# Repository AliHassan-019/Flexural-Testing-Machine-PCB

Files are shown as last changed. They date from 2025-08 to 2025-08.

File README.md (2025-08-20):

# Flexural Testing Machine — Control PCB

**Main control board for a catheter flexural/kink test rig with motion control, load-cell acquisition, and DWIN HMI.**

> **Open-hardware control PCB that advances a catheter via stepper, applies a defined bend angle via servo, and measures force with a 1 kg load cell to detect kink onset.**

---







---

## Quick Links

- [Schematic PDF](hardware/altium/flexural-pcb_rev1.0_sch.pdf)
- [PCB Layout](hardware/altium/flexural-pcb_rev1.0_pcb.pdf)
- [Fabrication Bundle](outputs/fab/flexural-pcb_rev1.0_fab.zip)
- [Assembly Bundle](outputs/assy/flexural-pcb_rev1.0_assy.zip)
- [Issues](../../issues)
- [Discussions](../../discussions)

---

## Table of Contents

1. [Overview](#overview)
2. [Safety & Regulatory Notice](#safety--regulatory-notice)
3. [Highlights / Features](#highlights--features)
4. [System / Block Diagram](#system--block-diagram)
5. [Power Architecture](#power-architecture)
6. [Schematic Overview](#schematic-overview)
7. [Connectors & Pinouts](#connectors--pinouts)
8. [Bill of Materials (BOM)](#bill-of-materials-bom)
9. [PCB Stackup & Rules](#pcb-stackup--rules)
10. [Layout Notes & 3D/Mechanical](#layout-notes--3dmechanical)
11. [EDA Tooling & Directory Structure](#eda-tooling--directory-structure)
12. [Design Rules & Constraints](#design-rules--constraints)
13. [Manufacturing: Fabrication Outputs](#manufacturing-fabrication-outputs)
14. [Manufacturing: Assembly Outputs](#manufacturing-assembly-outputs)
15. [DFM / DFT Guidance](#dfm--dft-guidance)
16. [Programming & Interfaces](#programming--interfaces)
17. [Calibration & Bring-Up](#calibration--bring-up)
18. [Validation & Test Records](#validation--test-records)
19. [Known Issues / Errata](#known-issues--errata)
20. [Roadmap](#roadmap)
21. [Contributing](#contributing)
23. [License](#license)
24. [Acknowledgments & Citation](#acknowledgments--citation)
25. [Changelog](#changelog)

---

## Overview

The **Flexural Testing Machine — Control PCB** is the main controller for a bench-top R&D device designed to measure the force at which catheters begin to kink under controlled bending. The PCB orchestrates the workflow: advancing the catheter, bending to a preset angle, acquiring force data, detecting kink onset, graphing/logging results, and reporting. Not intended for clinical or patient use.

**Workflow Summary:**
1. Advance catheter via stepper motor.
2. Bend catheter to defined angle using servo.
3. Acquire force via load cell and NAU7802 AFE.
4. Detect kink onset (force spike/drop).
5. Display/log results via DWIN HMI and USB.
6. Stop and report.

---

## Safety & Regulatory Notice

> ⚠️ **For R&D bench testing only; NOT a clinical device.**
>
> - Observe electrical safety protocols.
> - Beware of pinch hazards and motorized motion.
> - No claim of compliance with IEC/ISO standards.
> - References to standards are for design context only.

---

## Highlights / Features

- **MCU:** STM32L432KBT6 (Cortex-M4F, 80 MHz, 256 KB Flash, 64 KB SRAM, LQFP-32)
- **HMI:** DWIN 4.3″ DGUS II TFT Touch (DMT48270T043, UART-TTL, 5 V)
- **Stepper Driver:** TB6600 external module (optocoupled, 24 V)
- **Servo Output:** PWM 50 Hz, 1–2 ms, 6 V rail
- **Force Sensor:** 1 kg 4-wire load cell (1.0–2.0 mV/V)
- **Load-Cell ADC/AFE:** NAU7802CGI (24-bit Δ-Σ, I²C, 3.3 V)
- **Power Input:** 24 V DC (20–26 V), reverse/surge protected
- **Regulators:** MP1584EN (24 V→6 V/5 V, 3 A), AP2112K-3.3 (600 mA), TPS7A2033PDBVR (300 mA, low-noise)
- **Level Shifting/Protection:** 74AHCT125N, SN74LVC2T45DCUR, TPD4E1U06DQAR
- **PC Interface:** CP2102N USB-UART, Micro-B
- **Programming:** 10-pin 1.27 mm Cortex-M SWD header
- **Clocks:** 32.768 kHz LSE, 8 MHz HSE (fitted)
- **Discrete IO:** Limit/Home switches (x2), E-Stop (ISO1212D, 24 V)
- **Connectors:** Phoenix MCV 5.08, JST-XH, Molex Micro-B
- **Protections/Filters:** MBRS340, TVS diodes, ferrite beads, bulk caps
- **Decoupling:** 100 nF + 4.7 µF per device, anti-aliasing RC
- **Form Factor:** 120 × 90 mm, 4× M3 mounting holes, 3 mm keep-outs

---

## System / Block Diagram

```mermaid
flowchart LR
  MCU[STM32L432KBT6]
  HMI[DWIN 4.3in DGUS HMI]
  AFE[NAU7802 Load Cell ADC]
  SERVO[Servo Header PWM 6V GND]
  TB6600[TB6600 Driver IO]
  SWD[SWD Programming]
  USB[CP2102N USB CDC]
  LC[1 kg Load Cell]
  VIN[24V Input]
  PROT[Reverse and TVS]
  B6[MP1584 6V 3A]
  B5[MP1584 5V 3A]
  LDOd[AP2112K 3.3V Digital]
  FB[Ferrite]
  LDOa[TPS7A2033 Analog]

  MCU --> HMI
  MCU --> AFE
  MCU --> SERVO
  MCU --> TB6600
  MCU --> SWD
  MCU --> USB
  LC --> AFE
  VIN --> PROT
  PROT --> B6
  PROT --> B5
  B6 --> SERVO
  B5 --> HMI
  B5 --> LDOd
  B5 --> FB
  FB --> LDOa
  LDOd --> MCU
  LDOa --> AFE

```

---

## Power Architecture

```mermaid
flowchart TD
  IN[24V DC Input 20-26V]
  P24[Protected 24V]
  V6[6V Servo Rail 3A]
  V5[5V Rail 3A]
  V33D[3.3V Digital]
  V33A[3.3V Analog]

  IN --> P24
  P24 --> V6
  P24 --> V5
  V5 --> V33D
  V5 --> V33A

```

---

## Schematic Overview

- **Pages:**
	- MCU Core & Clocks
	- Power & Regulation
	- TB6600 Stepper IO
	- Servo Output
	- Load Cell & NAU7802 AFE
	- DWIN HMI UART
	- USB/CP2102N
	- SWD Programming
	- E-Stop & Limit Switches
- **Key Circuits:**
	- Reset: NRST RC (10 kΩ/100 nF)
	- BOOT0: 10 kΩ pulldown
	- Decoupling: 100 nF at each VDD, 4.7 µF bulk per IC
	- Anti-aliasing: 1 kΩ/0.1 µF on load cell SIG±

---

## Connectors & Pinouts

| Name | RefDes | Type | Pitch | Pin# | Signal(s) | Dir | Voltage | Notes |
|---|---|---|---|---|---|---|---|---|
| Power In | J1 | Phoenix MCV  | 5.08  | 2 | +24V, GND | In | 24 V | Reverse/surge protected |
| TB6600 PUL | J2 | Phoenix MCV  | 5.08  | 2 | PUL+, PUL− | Out | 5 V | Optocoupled, level shifted |
| TB6600 DIR | J3 | Phoenix MCV  | 5.08  | 2 | DIR+, DIR− | Out | 5 V | Optocoupled, level shifted |
| TB6600 ENA | J4 | Phoenix MCV  | 5.08  | 2 | ENA+, ENA− | Out | 5 V | Optocoupled, level shifted |
| Servo | J5 | JST-XH | 2.54  | 3 | PWM, +6V, GND | Out | 6 V | Standard RC servo |
| Load Cell | J6 | JST-XH | 2.54  | 6 | EX+, EX−, SIG+, SIG−, SEN+, SEN− | In | 3.3 V | 4-wire, shielded |
| DWIN HMI | J7 | JST-XH | 2.54  | 4 | 5V, GND, TXD, RXD | Bi | 5 V/3.3 V | UART, level shifted |
| Limit/Home | J8/J9  | JST-XH | 2.54  | 3 | GND, SIG, 3.3V | In | 3.3 V | RC debounce, pull-up |
| E-Stop | J10 | Phoenix MCV  | 5.08  | 2 | 24V, GND | In | 24 V | ISO1212D input |
| USB | J11 | Molex Micro-B| — | 5 | VBUS, D+, D−, ID, GND | Bi | 5 V | CP2102N bridge |
| SWD | J12 | Samtec FTSH  | 1.27  | 10 | SWDIO, SWCLK, NRST, GND, 3.3V | Bi | 3.3 V | Programming/debug |

---

## Bill of Materials (BOM)

| Item | Qty | Designators | Value/Spec | Description | Package | Manufacturer | MPN | Alt MPN | Distributor | Lifecycle | Notes | Status |
|---|-----|---|---|---|---|---|-----|---|---|---|---|---|
| MCU | 1 | U1 | STM32L432KBT6 | ARM Cortex-M4F, 80 MHz | LQFP-32 | STMicro | STM32L432KBT6 | — | Digi-Key | Active | Main controller | Fitted |
| HMI | 1 | LCD1 | DMT48270T043 | 4.3" TFT Touch | — | DWIN | DMT48270T043 | — | DWIN | Active | UART-TTL | Fitted |
| Stepper Driver | 1 | — | TB6600 | External module | — | Toshiba | TB6600 | — | Amazon | Active | Optocoupled | Fitted |
| Servo | 1 | — | Standard RC | PWM 50 Hz | — | Futaba | S3003 | MG995 | Amazon | Active | 6 V rail | Fitted |
| Load Cell | 1 | — | 1 kg | 4-wire, 1.0–2.0 mV/V | — | CZL | CZL635 | — | AliExpress | Active | Shielded | Fitted |
| Load Cell AFE | 1 | U2 | NAU7802CGI | 24-bit Δ-Σ ADC | TSSOP-16 | Nuvoton | NAU7802CGI | — | Digi-Key | Active | I²C | Fitted |
| USB-UART | 1 | U3 | CP2102N-A02-GQFN20 | USB bridge | QFN-20 | Silicon Labs | CP2102N-A02-GQFN20 | — | Digi-Key | Active | Micro-B | Fitted |
| SWD Header | 1 | J12 | FTSH-105-01-F-D-K | 10-pin, 1.27 mm | — | Samtec | FTSH-105-01-F-D-K | — | Digi-Key | Active | Programming | Fitted |
| Buck Regulator | 2 | U4/U5 | MP1584EN | 24V→6V/5V, 3A | SOIC-8 | MPS | MP1584EN | — | Digi-Key | Active | Servo/HMI rails | Fitted |
| LDO (Digital) | 1 | U6 | AP2112K-3.3 | 5V→3.3V, 600mA | SOT-23-5 | Diodes Inc. | AP2112K-3.3 | — | Digi-Key | Active | Digital 3.3V | Fitted |
| LDO (Analog) | 1 | U7 | TPS7A2033PDBVR | 5V→3.3V, 300mA | SOT-23-5 | TI | TPS7A2033PDBVR | — | Digi-Key | Active | Analog 3.3V | Fitted |
| Level Shifter | 1 | U8 | 74AHCT125N | 5V, 3.3V logic | DIP-14 | Nexperia | 74AHCT125N | — | Digi-Key | Active | TB6600 IO | Fitted |
| UART Translator | 1 | U9 | SN74LVC2T45DCUR | Bi-dir, 3.3V↔5V | VSSOP-8 | TI | SN74LVC2T45DCUR | — | Digi-Key | Active | HMI UART | Fitted |
| ESD Protection | 1 | U10 | TPD4E1U06DQAR | USB ESD | QFN-10 | TI | TPD4E1U06DQAR | — | Digi-Key | Active | USB | Fitted |
| E-Stop Input | 1 | U11 | ISO1212D | 24V digital in | SOIC-8 | TI | ISO1212D | — | Digi-Key | Active | Galvanic | Fitted |
| LSE Crystal | 1 | Y1 | ABS25-32.768KHZ-1-T | 32.768 kHz | — | Abracon | ABS25-32.768KHZ-1-T | — | Digi-Key | Active | RTC | Fitted |
| HSE Crystal | 1 | Y2 | ABM8G-8.000MHZ-18-D2Y-T | 8 MHz | — | Abracon | ABM8G-8.000MHZ-18-D2Y-T | — | Digi-Key | Active | Fitted | Fitted |
| TVS Diode | 3 | D1/D2/D3 | SMBJ36A/SMBJ5.0A/SMAJ6.0A | TVS | SMB | Littelfuse | SMBJ36A | SMBJ5.0A | Digi-Key | Active | Surge/ESD | Fitted |
| Schottky Diode | 1 | D4 | MBRS340 | Reverse protection | DPAK | ON Semi | MBRS340 | — | Digi-Key | Active | Input | Fitted |
| Ferrite Bead | 1 | FB1 | BLM21PG121SN1D | 120 Ω @ 100 MHz | 0805 | Murata | BLM21PG121SN1D | — | Digi-Key | Active | Analog 3.3V | Fitted |
| Bulk Cap | 4 | C1–C4 | 470 µF | Low-ESR | Radial | Panasonic | EEU-FR1V471 | — | Digi-Key | Active | Power rails | Fitted |
| Ceramic Cap | 8 | C5–C12 | 10 µF | X7R | 1206 | Murata | GRM31CR71A106KA01L | — | Digi-Key | Active | Regulator output | Fitted |
| Decoupling Cap | 12 | C13–C24 | 100 nF | X7R | 0603 | Murata | GRM188R71C104KA01D | — | Digi-Key | Active | VDD pins | Fitted |
| Anti-aliasing RC | 2 | R1/R2, C25/C26 | 1 kΩ/0.1 µF | SIG± | 0603 | Vishay/Murata | CRCW06031K00FKEA/GRM188R71C104KA01D | — | Digi-Key | Active | AFE input | Fitted |
| Connector (Power) | 1 | J1 | 1935174 | 2-pin, 5.08 mm | — | Phoenix | 1935174 | — | Digi-Key | Active | Power In | Fitted |
| Connector (TB6600) | 3 | J2–J4 | 1935174 | 2-pin, 5.08 mm | — | Phoenix | 1935174 | — | Digi-Key | Active | Stepper IO | Fitted |
| Connector (Servo) | 1 | J5 | B3B-XH-A | 3-pin, 2.54 mm | — | JST | B3B-XH-A | — | Digi-Key | Active | Servo | Fitted |
| Connector (Load Cell) | 1 | J6 | B6B-XH-A | 6-pin, 2.54 mm | — | JST | B6B-XH-A | — | Digi-Key | Active | Load cell | Fitted |
| Connector (HMI) | 1 | J7 | B4B-XH-A | 4-pin, 2.54 mm | — | JST | B4B-XH-A | — | Digi-Key | Active | HMI | Fitted |
| Connector (Limit) | 2 | J8/J9 | B3B-XH-A | 3-pin, 2.54 mm | — | JST | B3B-XH-A | — | Digi-Key | Active | Limit/Home | Fitted |
| Connector (USB) | 1 | J11 | 47346-0001 | Micro-B | — | Molex | 47346-0001 | — | Digi-Key | Active | USB | Fitted |
| Mounting Hole | 4 | H1–H4 | M3 | — | — | — | — | — | — | — | 5 mm offset | Fitted |

---

## PCB Stackup & Rules

- **Layers:** 4 (L1 Top signals, L2 GND, L3 Power, L4 Bottom signals)
- **Min trace/space:** 4/4 mil
- **Min via drill:** 0.2 mm; annular ring ≥ 0.1 mm; tented vias
- **Copper:** 1 oz outer/inner
- **Creepage/clearance:** ≥ 1.0 mm (≥24 V to logic), ≥ 2.0 mm (input)
- **Net classes:** Analog_AFE_3V3 (GND moat), Digital_3V3, HMI_5V, Servo_6V, Motor_24V
- **EMC/ESD:** TVS near connectors, short returns, stitching caps at ground splits

---

## Layout Notes & 3D/Mechanical

- **Board size:** 120 × 90 mm
- **Mounting:** 4× M3 holes, 5 mm offset, 3 mm keep-outs
- **Placement:** All user connectors on edges, silkscreen labels, polarity arrows
- **Return paths:** Short, direct for high-current rails
- **Thermal:** Bulk caps per rail, thermal vias under regulators

**Reference Images:**

<div align="center">
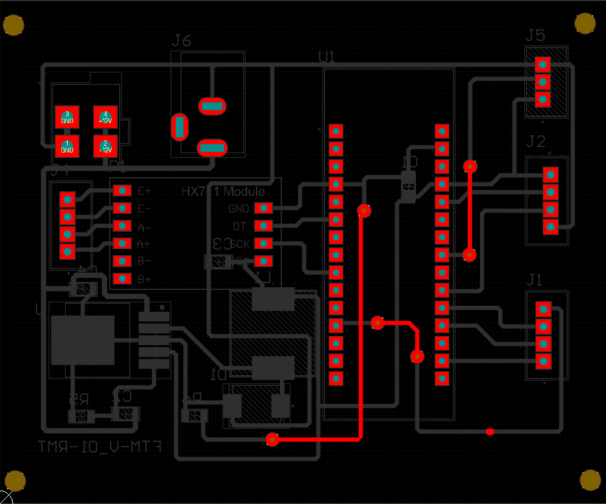
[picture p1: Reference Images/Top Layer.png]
Top Layer PCB
	
	<br>
	<em><strong>Top Layer:</strong> Shows the signal routing, component placement, and silkscreen for all user connectors and critical nets.</em>
</div>

<div align="center">
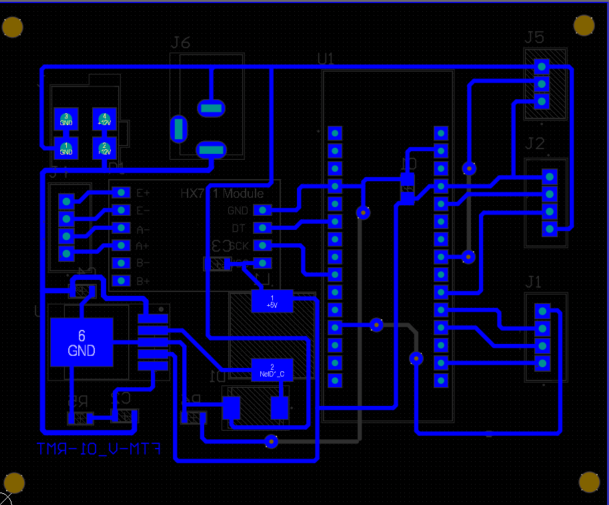
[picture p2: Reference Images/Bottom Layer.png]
Bottom Layer PCB
	
	<br>
	<em><strong>Bottom Layer:</strong> Highlights ground plane continuity, return paths, and keep-out zones for mounting hardware.</em>
</div>

<div align="center">
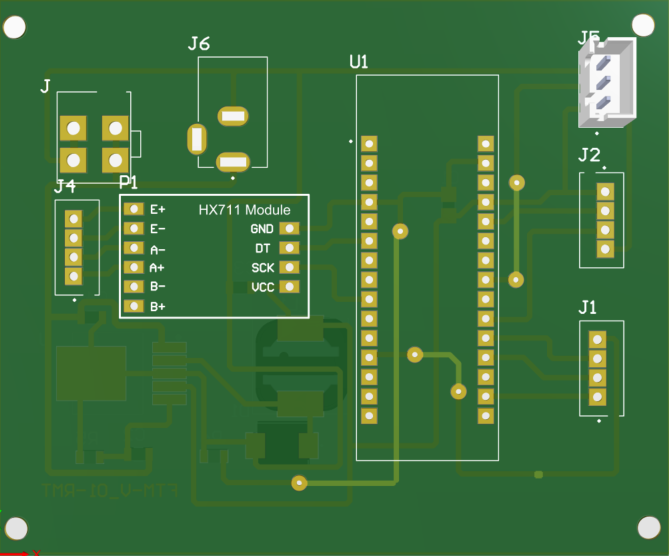
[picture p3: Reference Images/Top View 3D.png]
Top View 3D
	
	<br>
	<em><strong>Top View 3D:</strong> 3D render of the assembled PCB, showing connector orientation and mechanical features for enclosure integration.</em>
</div>

<div align="center">
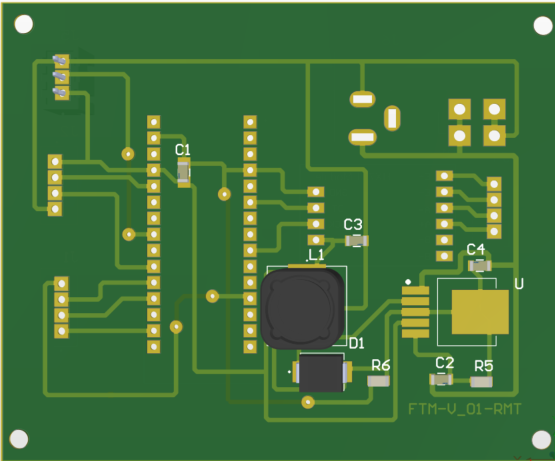
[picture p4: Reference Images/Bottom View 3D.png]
Bottom View 3D
	
	<br>
	<em><strong>Bottom View 3D:</strong> 3D render from below, illustrating mounting hole placement and overall board profile.</em>
</div>

---

## EDA Tooling & Directory Structure

- **Tool:** Altium Designer
- **Repo Tree:**
	```
	hardware/altium/
		├── flexural-pcb_rev1.0.PrjPcb
		├── flexural-pcb_rev1.0.SchDoc
		├── flexural-pcb_rev1.0.PcbDoc
		├── flexural-pcb_rev1.0_sch.pdf
		├── flexural-pcb_rev1.0_pcb.pdf
	outputs/fab/
		└── flexural-pcb_rev1.0_fab.zip
	outputs/assy/
		└── flexural-pcb_rev1.0_assy.zip
	docs/images/
		├── flexural-pcb_rev1.0_3d.png
		├── flexural-pcb_rev1.0_top.png
		└── flexural-pcb_rev1.0_bottom.png
	rules/
		└── flexural-pcb_rev1.0.drc
	scripts/
		└── bom_export.py
	```

---

## Design Rules & Constraints

- **Net Classes:** Analog_AFE_3V3 (shielded), Digital_3V3, HMI_5V, Servo_6V, Motor_24V
- **Clearances:** ≥ 1.0 mm (≥24 V to logic), ≥ 2.0 mm (input)
- **Impedance:** USB FS single-ended 90 Ω not required
- **Trace Lengths:** HMI UART < 200 mm
- **Via Tenting:** Outer layers
- **Decoupling:** 100 nF + 4.7 µF per IC

---

## Manufacturing: Fabrication Outputs

- **Files:**
	- RS-274X Gerbers
	- Excellon drill
	- IPC-356 netlist
	- PDF fab notes
- **Bundle:** `/outputs/fab/flexural-pcb_rev1.0_fab.zip`

---

## Manufacturing: Assembly Outputs

- **Files:**
	- BOM CSV
	- Centroid (XYRS)
	- Assembly drawings PDF
	- Paste layers
- **Bundle:** `/outputs/assy/flexural-pcb_rev1.0_assy.zip`

---

## DFM / DFT Guidance

- **Fiducials:** 3× global, 1× per corner
- **Tooling Holes:** 2× 3 mm
- **Panelization:** 2-rail tabs, breakaway
- **Paste Reductions:** 10% for fine-pitch ICs
- **Thermal Pad Windowing:** N/A (no exposed pads)
- **Test Points:**

| Net | TP# | Tool | Notes |
|---|-----|---|---|
| 3.3V_AFE | TP1 | Probe | Analog rail |
| 5V_DIG | TP2 | Probe | Digital rail |
| 24V_MOTOR | TP3 | Probe | Motor supply |
| SWDIO | TP4 | SWD Probe | Programming |
| UART1_TX | TP5 | Probe | HMI TX |
| UART2_TX | TP6 | Probe | USB TX |

---

## Programming & Interfaces

- **SWD Pinout:** 10-pin, 1.27 mm (FTSH-105-01-F-D-K)
- **CP2102N Driver:** [Download](https://www.silabs.com/developers/usb-to-uart-bridge-vcp-drivers)
- **UART Defaults:** 115200 baud, N81
- **Boot Straps:** BOOT0 pulldown 10 kΩ, NRST RC 10 kΩ/100 nF

---

## Calibration & Bring-Up

**Checklist:**
1. **Power Rails:** All within ±5% of nominal
2. **Idle Current:** < 100 mA (no motors/servo)
3. **AFE Zero Offset:** ±10 counts (NAU7802, no load)
4. **UART Loopback:** TX/RX OK at 115200 baud
5. **Servo PWM:** 20 ms period, 1–2 ms pulse
6. **Stepper IO:** TB6600 inputs toggle, opto OK
7. **Limit/Home:** Active-low, debounce verified
8. **E-Stop:** ISO1212D output active-high

---

## Validation & Test Records

| Test | Method | Acceptance Threshold |
|---|---|---|
| Ripple (3.3V) | Scope | < 50 mVpp |
| Temp (MCU) | IR Camera | < 60°C at max load |
| IO Timing | Logic Analyzer| < 1 µs jitter (step/dir) |
| E-Stop Latency  | Scope | < 10 ms |

---

## Known Issues / Errata

- None known as of Rev 1.0

---

## Roadmap

- Add isolated 24 V input stage
- Add second load-cell channel
- Expand HMI page set for advanced logging
- Integrate CAN bus for multi-axis rigs

---

## Contributing

- Use **Conventional Commits** for all changes.
- Schematic: hierarchical sheets, clear net naming.
- PCB: layer conventions, keep-out zones.
- Library: prefer manufacturer symbols/footprints.

---

## Security & Safety Reporting

## License



This project is licensed under the **CERN Open Hardware License v2 - Strongly Reciprocal (OHL-S v2)**.  
See [LICENSE](LICENSE) for full terms.

---

## Acknowledgments & Citation

README scaffolded with assistance from **GPT-5 Thinking**.

---

## Changelog

### Rev 1.0 — Initial Release (2025-08-20)
- First public release of schematic, PCB, BOM, and documentation.
- All features and protections as described above.

---

<div align="center">
	
	<br>
	<strong>Thank you for using and contributing to open hardware.<br>
	For questions, improvements, or collaboration, please open an issue or discussion.<br>
	<br>
	<em>Made with Altium Designer &mdash; Empowering Innovation in Medical R&D</em>
	</strong>
</div>

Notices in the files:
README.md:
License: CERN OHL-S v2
